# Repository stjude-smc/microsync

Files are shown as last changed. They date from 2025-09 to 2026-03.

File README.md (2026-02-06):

# `microsync` — Microscope Control with Microsecond Precision

**Author:** Roman Kiselev  
**License:** Apache 2.0  
**URL:** [https://github.com/stjude-smc/microsync](https://github.com/stjude-smc/microsync)





## 🚀 Quick Start

Upload `microsync-<x.y.z>.bin` firmware file to Arduino Due (e.g. using [BOSSA](https://github.com/shumatech/BOSSA/releases)).

Install Python `microsync` module.

```python
from microsync import SyncDevice

# Connect to device
sd = SyncDevice("COM4")  # or "/dev/ttyUSB0" on Linux

# Schedule a laser pulse
sd.pos_pulse("D8", 1000, ts=1000)  # 1ms pulse on D8 after 1ms delay
sd.go()  # Start execution
```

**📖 [Full Documentation](https://stjude-smc.github.io/microsync/) | 📓 [Interactive Demo](python/sync%20device%20demo.ipynb)**

## Overview & System Architecture

This project is a high-precision sync device for advanced microscope control, built around an Arduino Due (32-bit ARM Cortex-M3). It combines:

- **Firmware (C++):** Handles real-time event scheduling, pin control, and safety interlocks directly on the microcontroller. Uses a priority queue to manage up to 450 timed events (e.g., laser pulses, camera triggers) with microsecond accuracy.
- **Python API:** Lets you easily talk to the device, schedule events, and run complex acquisition protocols from your computer.

The device connects to your computer via UART (115,200 baud). All timing and pin logic runs on the microcontroller for reliable, low-latency operation.



*Color legend:* green – software components, yellow – microcontroller peripherals, purple – external hardware.

## ✨ Features

- **Microsecond-precision event scheduling** (pulses, toggles, pin set/reset, bursts)
- **Priority event queue** with hardware-timed execution
- **Laser shutter and interlock safety logic**
- **Support for advanced acquisition modes** (continuous, stroboscopic, ALEX)
- **Interactive event visualization** with Bokeh (zoom, pan, hover tooltips)
- **Comprehensive Python API** with logging and context management
- **Extensive examples and documentation in Jupyter notebook**

## 🔧 Hardware

- **Platform:** Arduino Due (32-bit SAM3X8E ARM Cortex-M3 microcontroller)

Arduino Due Board

*Arduino Due board - the hardware platform for microsync*

- **Key Pins: (configurable in `globals.h`)**
  - **Laser shutters:** D8 (Cy2), D9 (Cy3), D10 (Cy5), D11 (Cy7)
  - **Camera trigger:** D7
  - **Error indicator:** D51
  - **Debug pin:** D53
  - **Interlock:** D12 (input), D13 (output). If they are not connected, the laser shutters are disabled.
  - **Burst pulse:** D5
  - **See** `doc/Arduino Due pinout.pdf` and `microsync/src/globals.h` for full pin mapping.
  - **Note** - pins D35-D38 are reserved as inputs for future use. These pins, as well as interlock, error, and debug pins are unavailable as signal outputs because of their special functions.

## Firmware Upload
Upload `microsync-<x.y.z>.bin` to your Arduino Due using BOSSA or Atmel-ICE with Microchip Studio.

### Uploading firmware with BOSSA (no extra hardware required)

1. Download BOSSA from https://github.com/shumatech/BOSSA/releases (pick the right binary for your OS).
2. Connect Due to your computer, use the USB port next to the power jack.
3. Find newly created Arduino Due COM port (e.g. in the Device manager).
4. On your Due, press and hold **Erase** button for at least 0.5 seconds. This will wipe the current firmware and the microcontroller will enter the programming mode.

#### Upload via BOSSA GUI
1. Run BOSSA GUI.
2. Select the correct COM port.
3. Select `microsync-<x.y.z>.bin` file.
4. **Important**: Check the "Boot from Flash" option (this sets GPNVM0=1).
5. Click "Write".

#### Upload via command line
1. Put `bossac.exe` (or `bossac` on Mac/Linux) and `microsync-<x.y.z>.bin` in the same folder.
2. Open a terminal in that folder and run (replace `<COM-PORT>` with the actual COM port of your Due):

```sh
bossac.exe -e -w -v -b microsync-<x.y.z>.bin -p <COM-PORT>
```

### Uploading firmware with Microchip Studio using Atmel-ICE debugger
1. Connect Atmel-ICE SAM connector to JTAG header on your Due.
2. Connect Atmel-ICE to your computer.
3. Power up your Due with a USB cable.
4. Open Microchip Studio.
5. Open the Device Programming dialog (Ctrl+Shift+P).
6. Select Atmel-ICE tool, `ATSAM3X8E` device, JTAG interface, click "Apply".
7. Go to "Memory" tab, select `microsync-{version}.bin` file, click "Program".

### Communication Protocol & Data Structure

The device communicates via UART at 115,200 baud using a fixed-length 24-byte packet format. Each packet contains a command and associated parameters for precise event scheduling. All 24 bytes of a packet must arrive together, with no delay longer than 25 ms between individual bytes; otherwise, the packet is considered incomplete and will be discarded.

Data Packet Structure

**Packet Format:**
- **Command (4 bytes):** 3-character command string, null-terminated
- **Argument 1 (4 bytes):** First parameter (pin index, duration, etc.)
- **Argument 2 (4 bytes):** Second parameter (additional settings)
- **Timestamp (4 bytes):** Scheduled time point of function call, in microseconds
- **Count (4 bytes):** Number of repetitions (0 = infinite)
- **Interval (4 bytes):** Time between repetitions in microseconds

**Startup Message:**
Upon opening of the COM port, the device resets and sends the startup message the includes the firmware version.
```
Sync device is ready. Firmware version: 2.4.0
```

## 🐍 Python Driver

### Installation

Requires Python 3.7+ and `pyserial`.  The `microsync` package is automatically published on Python Package Index (PyPI), so it can be installed with `pip`:

```bash
pip install microsync
```

*Note*: Releases are published to PyPI automatically when a new version is released (a new tag starting with `v` is pushed). The workflow [`.github/workflows/publish-pypi.yml`](.github/workflows/publish-pypi.yml) builds the package from `python/`, sets the version from the tag, and publishes it to PyPI.

### Python Module Structure

The Python driver consists of several modules:

- **`microsync.py`** - Main `SyncDevice` class and communication interface
- **`constants.py`** - Timing constants and system parameters
- **`props.py`** - Property definitions and system settings
- **`rev_pin_map.py`** - Hardware pin mapping (Arduino pin names to internal IDs)
- **`__version__.py`** - Version information and package metadata
- **`sync device demo.ipynb`** - Comprehensive Jupyter notebook with examples

### Basic Usage

```python
from microsync import SyncDevice

# Connect to the device (replace COM4 with your port)
sd = SyncDevice("COM4", log_file='print')  # log_file can be None, 'print', or a filename

# Get device status
print(sd.get_status())
print(sd.version)

# Set and get properties
print(sd.pulse_duration_us)
sd.pulse_duration_us = 1000

# Schedule a positive pulse on pin D8 (Cy2 laser shutter)
sd.pos_pulse("D8", 8000, N=120, interval=50000)
sd.go()
```

### Logging

- Set `log_file='print'` to print all communication.
- Set `log_file='filename.log'` to save to a file.

### Context Manager

Batch multiple commands for precise timing: all commands within the context manager are collected and sent together as a single data packet over UART, ensuring they are processed together on the device. This approach eliminates timing jitter caused by delays or variability in the host operating system, resulting in highly accurate event scheduling.

```python
with sd as dev:
    dev.pos_pulse("D7", 100000, N=10, interval=500000, ts=0)   # Camera trigger
    dev.pos_pulse("D8", 100000, N=10, interval=500000, ts=5000) # Cy2 laser
```

### Event Scheduling

- **Pulse:** `sd.pos_pulse(pin, duration, ts, N, interval)`
- **Toggle:** `sd.tgl_pin(pin, ts, N, interval)`
- **Set/Reset:** `sd.set_pin(pin, level, ts, N, interval)`
- **Enable/Disable Pin:** `sd.enable_pin(pin)`, `sd.disable_pin(pin)`
- **Clear/Stop/Go:** `sd.clear()`, `sd.stop()`, `sd.go()`

#### Event Queue & Execution System

The device uses a **priority queue** to manage event scheduling with microsecond precision. Each data packet received from the host is converted into an internal event structure for scheduling. The most significant change is the conversion of timestamp from 4-byte to 8-byte integer, as well as mapping of pins from name to internal IOPORT index.

**Internal Event Structure (28 bytes):**
- **Function pointer** (4 bytes) — what action to execute (`EventFunc func`)
- **Argument 1** (4 bytes) — first parameter for the function (e.g., pin number)
- **Argument 2** (4 bytes) — second parameter for the function (e.g., duration)
- **Timestamp** (8 bytes) — 64-bit absolute time when to execute (`ts64_cts`)
- **Count** (4 bytes) — number of repetitions remaining (`N`)
- **Interval** (4 bytes) — time between repetitions (`interv_cts`)

**Queue Operation:**
1. **Packet Processing:** 24-byte data packets are converted to 28-byte event structures
2. **Sorting:** Events are automatically sorted by timestamp (earliest first)
3. **Execution:** System timer triggers the next event at its exact timestamp
4. **Repetition:** Events with `N > 1` are rescheduled with updated timestamps
5. **Precision:** Hardware timer ensures microsecond-accurate execution
6. **Capacity:** Up to 450 events can be queued simultaneously

**Example:** When you schedule multiple events, they're automatically ordered and executed in time sequence, regardless of the order they were submitted. If two events have exactly the same timestamp, their execution order is undefined.



### Laser Shutter and Interlock

- **Open/Close shutters:** `sd.open_shutters(mask)`, `sd.close_shutters(mask)`
- **Select lasers:** `sd.selected_lasers = 0b0110` (bitmask: Cy2, Cy3, Cy5, Cy7)
- **Interlock:** `sd.interlock_enabled = True/False`

#### Laser Safety Interlock System

The device includes a sophisticated laser safety interlock that monitors the integrity of the laser safety circuit:

**Hardware Setup:**
- **Output pin (D13):** Sends heartbeat pulses every 25ms
- **Input pin (D12):** Monitors return signal from interlock circuit
- **External circuit:** Required between D12 and D13 for proper operation

**Operation:**
1. **Heartbeat Generation:** System sends pulse train on D13 (HIGH for 1.56ms, LOW for 23.44ms)
2. **Signal Monitoring:** System checks D12 at two critical moments:
   - When output goes LOW (should detect LOW on input)
   - When output goes HIGH (should detect HIGH on input)
3. **Safety Logic:** 
   - **Normal:** Both conditions met → Lasers enabled
   - **Fault:** Either condition fails → Lasers immediately disabled
   - Detects open circuits, short circuits, and missing connections

**Runtime Control:**
```python
sd.interlock_enabled = True  # set to False to ignore the interlock circuit
```

In practice, you want to have normally closed magnetic reed switches (such as [Magnasphere](https://magnasphere.com/product/s-series/)) installed on the doors of the microscope enclosure, connected in series.

### Acquisition Modes

The following high-level acquisition modes are provided as convenience functions for our pTIRF microscopes. Internally, each mode schedules a sequence of low-level events using the common event execution engine described above. This allows you to easily run complex imaging protocols, while retaining precise timing and coordination under the hood:

#### Continuous Imaging
- **Use case:** Continuous illumination with synchronous camera readout
- **Method:** `sd.start_continuous_acq(exp_time, N_frames, ts=0)`
- **Behavior:** Laser shutters remain open during entire acquisition, camera triggered at precise intervals
- **First frame:** Automatically discarded as it contains pre-acquisition noise



The diagram below was created with `EventVisualizer` Python class that uses Bokeh to show actual events scheduled on the microcontroller.


#### Stroboscopic/Timelapse Imaging  
- **Use case:** Brief laser illumination during each camera exposure
- **Method:** `sd.start_stroboscopic_acq(exp_time, N_frames, ts=0, frame_period=0)`
- **Behavior:** Laser pulse synchronized with camera exposure, followed by readout period
- **Timelapse:** Optional waiting period between frames when `frame_period > 0`

Image below shows stroboscopic acquisition diagram with Kinetix camera.



#### ALEX (Alternating Laser Excitation)

> **Note:** For ALEX, select lasers by setting `sd.selected_lasers` in Python (e.g., `sd.selected_lasers = 0b0110`), or send a `SET` command with the `rw_SELECTED_LASERS` property ID (from the `SysProps` enum) over UART.
- **Use case:** Multi-spectral imaging with alternating laser illumination
- **Method:** `sd.start_ALEX_acq(exp_time, N_bursts, ts=0, burst_period=0)`
- **Behavior:** Bursts of frames, each illuminated by different laser channel
- **Timelapse:** Optional waiting period between bursts when `burst_period > 0`

**NOTE** - stroboscopic and ALEX modes use level trigger, which behaves differently on Kinetix and Hamamatsu cameras.
When using Kinetix camera, set the camera triggering mode to "Level trigger overlap mode". It behaves similarly to continuous (rolling shutter) mode, enabling fast imaging. You will have to set Microsync `rw_CAM_LEVEL_TRIGGER_MODE` property to 1 (OVERLAP) to generate correct timings.



When using a Hamamatsu camera, set it to "Level trigger global reset mode" and set the `rw_CAM_LEVEL_TRIGGER_MODE` property to 2 (GLOBAL_RESET) to generate correct timings.



### Status and Events

- **Get all scheduled events:** `sd.get_events(unit="us"|"ms")`
- **Check frames left:** `sd.N_frames_left()`

### Interactive Event Visualization

The `show_events()` method provides interactive visualization of scheduled events using Bokeh:

```python
# Create interactive plot
plot = sd.show_events()

# In Jupyter notebook, plot displays automatically
# Save to file
plot.save_plot("events.html")  # Interactive HTML
plot.save_plot("events.png")   # Static PNG
plot.save_plot("events.svg")   # Vector SVG
```

**Features:**
- **Interactive zoom and pan** - Examine precise timing details
- **Hover tooltips** - See exact timestamps and durations
- **State-based visualization** - Gray boxes show active states (HIGH pins, open shutters)

### Timing Configuration

**Note:** All timing parameters for `microsync` are specified in microseconds (µs).

Configure these timing parameters to match your hardware before starting acquisition:

```python
# Essential timing parameters (in microseconds)
sd.shutter_delay_us = 1300      # Laser shutter opening time
sd.cam_readout_us = 14000       # Camera readout duration (depends on ROI)
sd.pulse_duration_us = 800      # Default pulse duration

# Laser selection (bitmask: Cy2=bit0, Cy3=bit1, Cy5=bit2, Cy7=bit3)
sd.selected_lasers = 0b0110     # Enable Cy3 and Cy5 lasers
```

**Important Notes:**
- `shutter_delay_us` should match your laser shutter's actual opening time. Use an oscilloscope and a photodiode to measure it.
- `cam_readout_us` depends on camera ROI settings. See the camera manual to find out how to calculate or query it.
- Timing values persist between acquisitions until changed. They drop back to defaults after system reset.

## 📚 Examples

See [`python/sync device demo.ipynb`](python/sync%20device%20demo.ipynb) for a comprehensive, step-by-step tutorial with code, explanations, and advanced usage patterns.

## 📋 Properties

| ID | Property | Access | Description |
|----|---|---|---|
| 0  | `version` | Read-only  | Firmware version |
| 1  | `running` | Read-only  | System timer running status |
| 2  | `sys_timer_value` | Read-only  | System timer value (counter ticks) |
| 3  | `sys_timer_ovf_count` | Read-only  | System timer overflow count |
| 4  | `sys_time_ms` | Read-only  | System time (milliseconds) |
| 5  | `prescaler` | Read-only  | System timer prescaler |
| 6  | `pulse_duration_us` | R/W | Default pulse duration (microseconds) |
| 7  | `watchdog_timeout_ms` | Read-only  | Watchdog timeout (ms) |
| 8  | `N_events` | Read-only  | Number of events in queue |
| 9  | `interlock_enabled` | R/W | Laser interlock state (0=disabled) |
| 10 | `selected_lasers` | R/W | Bitmask of enabled laser channels |
| 11 | `open_shutters` | Write-only | Open specified laser shutters |
| 12 | `close_shutters` | Write-only | Close specified laser shutters |
| 13 | `shutter_delay_us` | R/W | Shutter delay (microseconds) |
| 14 | `cam_readout_us` | R/W | Camera readout time (microseconds) |
| 15 | `cam_global_rst` | R/W | Global reset in level trigger mode (bool) |

## 📖 Documentation

📖 **[Full Documentation](https://stjude-smc.github.io/microsync/)** - Complete API reference, user guides, and examples

- **Firmware:** See `microsync/src/` for C++ source and hardware logic.
- **Python API:** See `python/microsync.py` and the Jupyter notebook.
- **Data packet structure:** See `doc/data packet structure.xlsx`.

### Building Documentation

This project includes comprehensive Sphinx/Doxygen documentation that combines Python API documentation with C++ firmware documentation.

#### Prerequisites

**Doxygen:** Required for C++ documentation generation
   - **Windows:** Download and install from [Doxygen website](https://www.doxygen.nl/download.html)
   - **Linux:** `sudo apt-get install doxygen` (Ubuntu/Debian) or `sudo yum install doxygen` (CentOS/RHEL)
   - **macOS:** `brew install doxygen`

#### Building the Documentation

Run the automated build script from the project root:

```bash
python build_docs.py
```

The documentation will be available at `sphinx_docs/_build/html/index.html`. The generated documentation includes:
- **Python API Reference:** Auto-generated from docstrings in the Python modules
- **C++ API Reference:** Generated from firmware header files using Doxygen + Breathe
- **User Guide:** Manual documentation and examples
- **Firmware Architecture:** Detailed explanations of the C++ implementation

The Sphinx documentation automatically builds and deploys to GitHub pages on every push to branches `develop` and `master` via GitHub actions.

## 🔧 Firmware Development

### Building the Firmware

The firmware is built using Microchip Studio or compatible IDEs:

1. **Open the project:** Load `microsync.atsln` in Microchip Studio
2. **Build target:** Select "Release" configuration
3. **Upload:** Use the Atmel ICE debugger, connected via JTAG interface to the microcontroller board. Hit `Ctrl+Shift+P` to open the programming dialog.
4. **Debugging:** If you upload the "Debug" configuration, you can set a breakpoint and pause the code execution on Arduino Due when it's connected via JTAG to Atmel ICE. You will have a normal step-by-step debugging with the direct access to the device registers and memory via Microchip Studio . The caveat is that the hardware timers keep running while you're in the debug mode. Use an oscilloscope when verifying event order and timing in addition to the code debugging.

### Firmware Architecture

- **`main.cpp`:** Entry point and system initialization
- **`globals.h`:** Global definitions, pin mappings, and system settings
- **`events.h/cpp`:** Event scheduling and priority queue management
- **`uart_comm.h/cpp`:** Communication protocol implementation
- **`pins.h/cpp`:** Pin control and hardware abstraction
- **`interlock.h/cpp`:** Laser safety interlock logic (can be disabled)

### Features and Limitations

- **Event queue:** Maximum 450 scheduled events (vs. 4 hardware timers in legacy)
- **Jitter:** Events scheduled within ~10µs of each other may have timing jitter
- **Overload protection:** A watchdog timer automatically resets the system if event queue overflows
- **Interlock:** Requires external circuit between D12 and D13 for laser safety
- **External triggers:** Not available yet, but possible to add. In the future, we could make it so the device reacts to changes on an input pin (like a button press or signal) and schedules events automatically.

**Note:** These limitations are significantly improved compared to the legacy 8-bit version, which had 4.19s exposure limits and 64µs timing resolution.

### Evolution from Legacy `sync_device`
This is the **second generation** of the microscope synchronization device, based on a 32-bit ARM microcontroller (Arduino Due). The first generation was based on Arduino Mega2560 (8-bit ATMega2560) and had fundamental limitations:

**Key Changes and Improvements in 32-bit Version:**
- **3.3V** logic – Arduino Due uses 3.3V CMOS logic levels for digital I/O, whereas the Arduino Mega2560 uses 5V logic levels
- **Microsecond precision** (vs. 64µs steps in 8-bit version)
- **No 4.19s exposure time limit** (vs. 16-bit timer limitation)
- **Event-driven architecture** with priority queue (vs. fixed state machine)
- **Up to 450 scheduled events** (vs. limited to 4 hardware timers)
- **Advanced acquisition modes** with precise timing control
- **Safety interlocks** for laser protection
- **Modern Python API** with context management and logging

**Legacy Repository:** The original 8-bit version is available at [sync_device_8bit_legacy](https://github.com/stjude-smc/sync_device_8bit_legacy) for reference.

## 📝 License

Apache 2.0.  
(c) Roman Kiselev, St. Jude Children's Research Hospital

## 🙏 Acknowledgments

- Based on Atmel SAM3X8E microcontroller (Arduino Due board)
- Uses `ASF` (Atmel Software Framework)
- See `/doc` for datasheets and pinouts

---

**For questions or contributions, please open an issue or pull request on [GitHub](https://github.com/stjude-smc/microsync).**

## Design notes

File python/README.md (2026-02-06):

# `microsync` — Python driver for microscope synchronization device

**Python driver for `microsync` — a universal 32-bit Arduino Due-based triggering device**. Control lasers, cameras, and timing with microsecond precision.

- **Full documentation:** [stjude-smc.github.io/microsync](https://stjude-smc.github.io/microsync/)
- **Repository:** [github.com/stjude-smc/microsync](https://github.com/stjude-smc/microsync)

## Install

Requires Python 3.7+ and `pyserial` (installed automatically):

```bash
pip install microsync
```

## Quick start

Upload the microsync firmware to an Arduino Due, then:

```python
from microsync import SyncDevice

sd = SyncDevice("COM4")   # or "/dev/ttyUSB0" on Linux
sd.pos_pulse("D8", 1000, ts=1000)   # 1 ms pulse on D8 after 1 ms delay
sd.go()
```

## Features

- Microsecond-precision event scheduling (pulses, toggles, camera triggers)
- Laser shutter and interlock safety logic
- Acquisition modes: continuous, stroboscopic, ALEX
- Interactive event visualization (Bokeh)
- Context manager for jitter-free batch commands

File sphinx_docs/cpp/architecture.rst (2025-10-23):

C++ Firmware Architecture
=========================

Overview
--------

The microsync firmware is built on the Arduino Due platform using the SAM3X8E ARM Cortex-M3 microcontroller. The firmware provides microsecond-precision timing control for microscope synchronization with a focus on safety, reliability, and performance.

System Architecture
-------------------

System architecture diagram

Color legend: green – software components, yellow – microcontroller peripherals, purple – external hardware.

Core Components
---------------

Event System
^^^^^^^^^^^^

The heart of the synchronization system is the priority queue-based event scheduler:

- **Priority Queue**: Orders events by timestamp for precise execution
- **Event Processing**: Handles up to 450 scheduled events
- **Microsecond Precision**: 64-bit timestamp system with overflow handling
- **Real-time Execution**: Interrupt-driven event processing

.. code-block:: cpp

   // Event structure for priority queue
   struct Event {
       uint8_t func;           // Function to execute
       uint8_t arg1, arg2;     // Function arguments
       uint64_t ts64_cts;      // 64-bit timestamp in clock ticks
       uint16_t N;             // Number of repetitions
       uint32_t interv_cts;    // Interval between repetitions
   };

Communication System
^^^^^^^^^^^^^^^^^^^^

UART-based communication protocol for host-device interaction:

- **Baud Rate**: 115,200 bps
- **Protocol**: Command-response with error handling
- **Buffer Management**: Ring buffer with overflow protection
- **Timeout Handling**: Automatic detection of incomplete transmissions

.. code-block:: cpp

   // UART communication functions
   void init_uart_comm(void);
   void uart_tx(const char* data, uint16_t len);
   void process_uart_rx(void);

Safety Systems
^^^^^^^^^^^^^^

Laser safety interlock system with hardware and software protection:

- **Hardware Interlock**: D12/D13 circuit monitoring
- **Software Timer**: 1.56ms heartbeat generation
- **Automatic Shutdown**: Disables lasers on interlock failure
- **Runtime Control**: Enable/disable via software

.. code-block:: cpp

   // Interlock control functions
   void init_interlock(void);
   void enable_lasers(void);
   void disable_lasers(void);

Hardware Interface
^^^^^^^^^^^^^^^^^^

Pin management and hardware abstraction layer:

- **Pin Mapping**: Arduino Due pin assignments
- **Laser Shutters**: D8 (Cy2), D9 (Cy3), D10 (Cy5), D11 (Cy7) - see ``globals.h``
- **Camera Trigger**: D7 - see ``globals.h``
- **Status LEDs**: Visual feedback and debugging

.. code-block:: cpp

   // Pin control functions
   void init_pins(void);
   void set_pin(uint8_t pin, bool state);
   void toggle_pin(uint8_t pin);

Memory Management
-----------------

Optimized memory usage for embedded constraints:

- **Static Allocation**: Pre-allocated buffers and structures
- **Stack Management**: Careful stack usage monitoring
- **Heap Protection**: Out-of-memory handler with error reporting
- **Buffer Sizes**: Optimized for typical use cases

.. code-block:: cpp

   // Memory management
   #define MAX_N_EVENTS 450
   #define UART_BUFFER_SIZE 256
   #define WATCHDOG_TIMEOUT 1000  // ms

Error Handling
--------------

Comprehensive error detection and recovery:

- **Watchdog Timer**: System reset on software hang
- **Hard Fault Handler**: Graceful handling of hardware errors
- **UART Error Reporting**: Real-time error communication
- **LED Status**: Visual error indication

.. code-block:: cpp

   // Error handling functions
   void activate_watchdog(void);
   void err_led_on(void);
   void out_of_memory_handler(void);

Performance Characteristics
---------------------------

- **Event Scheduling**: Up to 450 events
- **Timing Precision**: Microsecond accuracy
- **Response Time**: < 1ms command processing
- **Memory Usage**: < 32KB RAM
- **CPU Utilization**: < 10% typical load

Build System
------------

The firmware is built using Microchip Studio with the following configuration:

- **Target**: Arduino Due (SAM3X8E)
- **Compiler**: ARM GCC
- **Optimization**: -O2 for performance
- **Debugging**: Full debug symbols in Debug build
- **Release**: Optimized for production use

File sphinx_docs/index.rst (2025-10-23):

Welcome to microsync documentation!
==========================================

**Version:** |version|  
**Author:** Roman Kiselev  
**License:** Apache 2.0

A high-precision synchronization device for advanced microscope control, based on a 32-bit ARM microcontroller (Arduino Due).

`View on GitHub <https://github.com/stjude-smc/microsync>`_

.. toctree::
   :maxdepth: 2
   :caption: Contents:

   installation
   quickstart
   api/index
   cpp/architecture
   cpp/firmware
   cpp_api/library_root

Overview
--------

This project provides firmware and a Python driver for a high-precision synchronization device designed for advanced microscope control. The device enables precise timing and coordination of lasers, shutters, cameras, and other peripherals with microsecond precision.

Key Features
^^^^^^^^^^^^

* **Microsecond-precision event scheduling** with priority queue system
* **Laser shutter and interlock safety logic**
* **Advanced acquisition modes** (continuous, stroboscopic, ALEX)
* **Comprehensive Python API** with logging and context management
* **Event-driven architecture** supporting up to 450 scheduled events
* **Safety interlocks** for laser protection

Hardware Platform
^^^^^^^^^^^^^^^^^

* **Microcontroller:** Arduino Due (SAM3X8E ARM Cortex-M3)
* **Logic Levels:** 3.3V CMOS
* **Communication:** UART at 115,200 baud
* **Key Pins:** Laser shutters (D8-D11), Camera trigger (D7), Interlock (D12/D13)

Python API
^^^^^^^^^^

The Python driver provides a high-level interface for controlling the device:

.. code-block:: python

   from microsync import SyncDevice
   
   # Connect to device
   sd = SyncDevice("COM4")
   
   # Schedule events
   sd.pos_pulse("D8", 1000, N=10, interval=50000)  # Pulse on D8 (Cy2 laser)
   sd.go()

For detailed API documentation, see :doc:`api/index`.

Installation
^^^^^^^^^^^^

.. code-block:: bash

   pip install pyserial
   # Copy python/ directory to your project

For complete installation instructions, see :doc:`installation`.

Quick Start
^^^^^^^^^^^

1. Connect laser shutters and cameras to the Arduino Due pins. Use LED during testing.
1. Connect Arduino Due via USB
2. Install Python dependencies
3. Import and use the SyncDevice class
4. Schedule events and start acquisition

See :doc:`quickstart` for a step-by-step guide.

Indices and tables
==================

* :ref:`genindex`
* :ref:`modindex`
* :ref:`search`

.. _GitHub: https://github.com/stjude-smc/microsync

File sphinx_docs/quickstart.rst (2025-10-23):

Quick Start Guide
=================

This guide will get you up and running with microsync in minutes. It covers the basic setup and common usage patterns.

Basic Setup
-----------

1. **Install the Python driver:**

   .. code-block:: bash

      pip install pyserial
      # Copy the python/ directory to your project

2. **Connect your Arduino Due:**

   .. code-block:: python

      from microsync import SyncDevice
      
      # Connect to device (replace COM4 with your port)
      sd = SyncDevice("COM4")
      print(f"Connected! Firmware version: {sd.version}")

Basic Event Scheduling
----------------------

**Simple Pulse Generation:**

.. code-block:: python

   # Generate a 1ms pulse on pin A0
   sd.pos_pulse("A0", 1000)
   sd.go()

**Repeating Events:**

.. code-block:: python

   # Generate 10 pulses, 1ms each, every 50ms
   sd.pos_pulse("A0", 1000, N=10, interval=50000)
   sd.go()

**Multiple Events:**

.. code-block:: python

   # Schedule multiple events
   sd.pos_pulse("A0", 1000, ts=0)      # At t=0
   sd.pos_pulse("A1", 1000, ts=5000)   # At t=5ms
   sd.pos_pulse("A2", 1000, ts=10000)  # At t=10ms
   sd.go()

**Using Context Manager for Precise Timing:**

.. code-block:: python

   # Batch commands for precise timing
   with sd as dev:
       dev.pos_pulse("A0", 1000, ts=0)
       dev.pos_pulse("A1", 1000, ts=5000)
       dev.pos_pulse("A2", 1000, ts=10000)
   # All commands sent together

Laser Control
--------------

**Basic Laser Shutter Control:**

.. code-block:: python

   # Open all laser shutters
   sd.open_shutters()
   
   # Close specific shutters (Cy2 and Cy5)
   sd.close_shutters(1 | 4)
   
   # Select which lasers are enabled
   sd.selected_lasers = 0b0110  # Enable Cy3 and Cy5

**Laser Interlock:**

.. code-block:: python

   # Check interlock status
   print(f"Interlock enabled: {sd.interlock_enabled}")
   
   # Disable interlock (for testing only)
   sd.interlock_enabled = False

Acquisition Modes
-----------------

**Continuous Imaging:**

.. code-block:: python

   # Configure timing
   sd.shutter_delay_us = 1300
   sd.cam_readout_us = 14000
   
   # Start continuous acquisition
   sd.start_continuous_acq(exp_time=200000, N_frames=15)
   sd.go()

**Stroboscopic Imaging:**

.. code-block:: python

   # Start stroboscopic acquisition
   sd.start_stroboscopic_acq(exp_time=200000, N_frames=15)
   sd.go()

**ALEX (Multi-spectral) Imaging:**

.. code-block:: python

   # Select lasers for ALEX
   sd.selected_lasers = 0b1111  # All lasers
   
   # Start ALEX acquisition
   sd.start_ALEX_acq(exp_time=50000, N_bursts=9)
   sd.go()

System Control
--------------

**Start/Stop Control:**

.. code-block:: python

   # Start processing events
   sd.go()
   
   # Stop processing (events remain in queue)
   sd.stop()
   
   # Resume processing
   sd.go()

**Event Management:**

.. code-block:: python

   # Clear all scheduled events
   sd.clear()
   
   # Check how many events are scheduled
   print(f"Events in queue: {sd.N_events}")
   
   # Get list of scheduled events
   events = sd.get_events("us")
   for event in events:
       print(f"{event.func} at {event.ts} {event.unit}")

**System Status:**

.. code-block:: python

   # Get detailed status
   print(sd.get_status())
   
   # Check if system is running
   print(f"System running: {sd.running}")
   
   # Get current system time
   print(f"System time: {sd.sys_time_s:.3f} seconds")

Configuration
-------------

**Timing Parameters:**

.. code-block:: python

   # Set default pulse duration
   sd.pulse_duration_us = 800
   
   # Set camera readout time
   sd.cam_readout_us = 14000
   
   # Set shutter delay
   sd.shutter_delay_us = 1300

**Logging:**

.. code-block:: python

   # Enable communication logging
   sd = SyncDevice("COM4", log_file="sync.log")
   
   # Or print to terminal
   sd = SyncDevice("COM4", log_file="print")

Common Patterns
---------------

**Timelapse Acquisition:**

.. code-block:: python

   # Stroboscopic with timelapse
   sd.start_stroboscopic_acq(
       exp_time=200000, 
       N_frames=5, 
       frame_period=1500000  # 1.5s between frames
   )
   sd.go()

**Multi-channel Control:**

.. code-block:: python

   # Control multiple pins simultaneously
   with sd as dev:
       dev.pos_pulse("D8", 1000, ts=0)      # Cy2 laser
       dev.pos_pulse("D9", 1000, ts=1000)   # Cy3 laser
       dev.pos_pulse("D10", 1000, ts=2000)  # Cy5 laser
       dev.pos_pulse("D7", 100, ts=500)     # Camera trigger

**Error Handling:**

.. code-block:: python

   try:
       sd = SyncDevice("COM4")
       sd.pos_pulse("A0", 1000)
       sd.go()
   except Exception as e:
       print(f"Error: {e}")
       # Handle error appropriately

Next Steps
----------

Now that you have the basics:

1. **Explore the API:** See :doc:`api/index` for complete documentation
2. **Try examples:** Check the Jupyter notebook for more complex scenarios
3. **Learn about hardware:** Review the README for connection details
4. **Understand firmware:** See the source code for technical details

**Need help?** Open an issue on GitHub or check the README.

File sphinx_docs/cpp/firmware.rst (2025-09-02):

Firmware Build and Deployment
=============================

Building the Firmware
---------------------

Prerequisites
^^^^^^^^^^^^^

- **Microchip Studio** (free download from Microchip)
- **Arduino Due board**
- **micro-USB cable**
- **Atmel ICE debugger** (optional, for debugging)

Project Structure
^^^^^^^^^^^^^^^^^

.. code-block:: text

   microsync/
   ├── main.cpp                # Main application entry point
   ├── src/
   │   ├── globals.h           # Global definitions and constants
   │   ├── events.h/cpp        # Event system implementation
   │   ├── uart_comm.h/cpp     # UART communication
   │   ├── interlock.h/cpp     # Laser safety interlock
   │   ├── pins.h/cpp          # Pin management
   │   ├── props.h/cpp         # System properties
   │   └── ASF/                # Atmel Software Framework
   └── microsync.atsln         # Microchip Studio solution

Build Configuration
^^^^^^^^^^^^^^^^^^^

**Debug Configuration:**

- Full debug symbols, you can set breakpoints in the code and step through the code running on the board.
- Optimization disabled
- Development and testing

**Release Configuration:**

- Optimized for performance (-O2)
- Minimal debug information, no breakpoints can be set.
- Production deployment
- Reduced memory footprint

Build Steps
^^^^^^^^^^^

1. **Open** `microsync.atsln` in Microchip Studio.
2. **Select** Debug or Release config (target: Arduino Due).
3. **Build** (F7).  
4. **Check** for `microsync.bin` in Debug/ or Release/ folder.

Upload Methods
--------------

See the :doc:`../installation#firmware-upload` section in the installation guide.

Troubleshooting
---------------

Common Issues
^^^^^^^^^^^^^

**Build Errors:**

- Check ASF framework installation
- Verify include paths
- Ensure all source files are included

**Upload Failures:**

- Check USB connection
- Verify COM port settings
- Ensure Arduino Due is in programming mode

**Runtime Issues:**

- Check power supply
- Verify pin connections
- Monitor UART output for errors

Debugging
---------

Debug Features
^^^^^^^^^^^^^^

- **Breakpoints:** Set in Microchip Studio
- **Variable Watch:** Real-time value inspection
- **Call Stack:** Function call history
- **Memory Inspection:** RAM and register values

Note that pausing the program will not stop the running system timers, and you're likely to miss scheduled events.

Version Management
------------------

Version Information
^^^^^^^^^^^^^^^^^^^

The firmware version is defined in `globals.h`:

.. code-block:: cpp

   #define VERSION "2.4.0"

Version Compatibility
^^^^^^^^^^^^^^^^^^^^^

- **Python Driver**: Must match major and minor firmware version
- **Protocol**: Backward compatible within major versions
- **Features**: New features require updates to Python driver

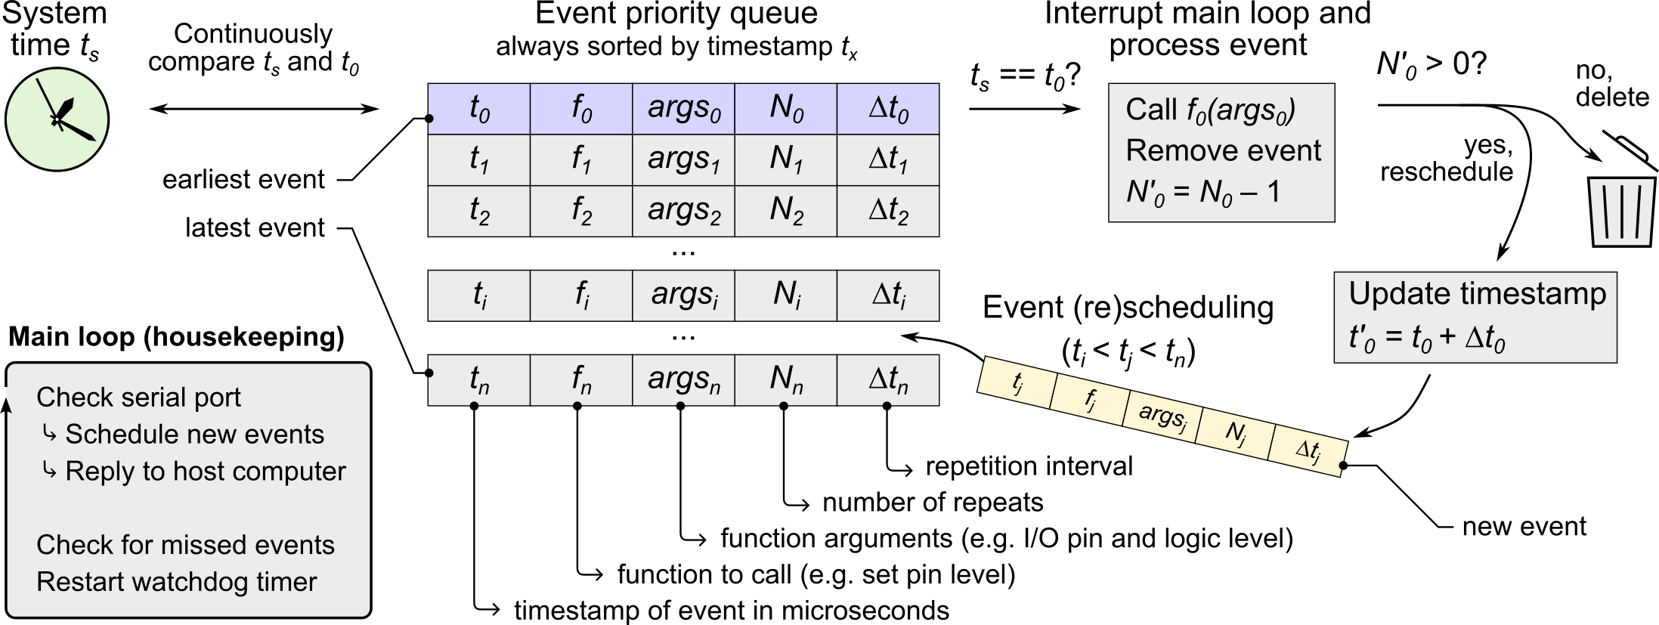
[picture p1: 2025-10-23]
doc/scheduler_architecture.png

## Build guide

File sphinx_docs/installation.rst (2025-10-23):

Installation Guide
==================

This guide covers the installation and setup of the microsync project, including both the Python driver and firmware.

Python Driver Installation
--------------------------

Prerequisites
^^^^^^^^^^^^^

* Python 3.7 or higher
* pip package manager
* Serial port access (for device communication)

Install Dependencies
^^^^^^^^^^^^^^^^^^^^

Install the required Python packages:

.. code-block:: bash

   pip install pyserial

Install the microsync Driver
^^^^^^^^^^^^^^^^^^^^^^^^^^^^^^^^^

**Option 1: Copy the Python directory**

.. code-block:: bash

   # Clone or download the repository
   git clone https://github.com/stjude-smc/microsync.git
cd microsync
   
   # Copy the python directory to your project
   cp -r python/ /path/to/your/project/
   
   # Or add to your Python path
   export PYTHONPATH="${PYTHONPATH}:/path/to/microsync/python"

**Option 2: Install as a package (recommended for development)**

.. code-block:: bash

   # From the project root directory
   pip install -e .

Verify Installation
^^^^^^^^^^^^^^^^^^^

Test that the driver can be imported:

.. code-block:: python

   from microsync import SyncDevice
   print("Installation successful!")

Firmware Installation
---------------------

Prerequisites
^^^^^^^^^^^^^

* Microchip Studio (free download from Microchip)
* Arduino Due board
* USB cable
* Atmel ICE debugger (optional, for debugging)

Build the Firmware
^^^^^^^^^^^^^^^^^^

1. **Open the project in Microchip Studio:**

   .. code-block:: bash

      # Open the solution file
      microsync.atsln

2. **Configure build settings:**

   - Set build target to "Release"
   - Ensure all dependencies are resolved

3. **Build the project:**

   - Press F7 or use Build → Build Solution
   - Verify successful compilation

Firmware Upload
^^^^^^^^^^^^^^

Upload `microsync-<x.y.z>.bin` to your Arduino Due using BOSSA or Atmel-ICE with Microchip Studio.

**Method 1: Using BOSSA (Recommended - No Extra Hardware Required)**

1. Download BOSSA from https://github.com/shumatech/BOSSA/releases (pick the right binary for your OS)
2. Connect Due to your computer, use the USB port next to the power jack
3. Find newly created Arduino Due COM port (e.g. in the Device manager)
4. On your Due, press and hold **Erase** button for at least 0.5 seconds. This will wipe the current firmware and the microcontroller will enter the programming mode

**Upload via BOSSA GUI:**

1. Run BOSSA GUI
2. Select the correct COM port
3. Select `microsync-<x.y.z>.bin` file
4. **Important**: Check the "Boot from Flash" option (this sets GPNVM0=1)
5. Click "Write"

**Upload via command line:**

1. Put `bossac.exe` (or `bossac` on Mac/Linux) and `microsync-<x.y.z>.bin` in the same folder
2. Open a terminal in that folder and run (replace `<COM-PORT>` with the actual COM port of your Due):

   .. code-block:: sh

      bossac.exe -e -w -v -b microsync-<x.y.z>.bin -p <COM-PORT>

**Method 2: Using Microchip Studio with Atmel-ICE Debugger**

1. Connect Atmel-ICE SAM connector to JTAG header on your Due
2. Connect Atmel-ICE to your computer
3. Power up your Due with a USB cable
4. Open Microchip Studio
5. Open the Device Programming dialog (Ctrl+Shift+P)
6. Select Atmel-ICE tool, `ATSAM3X8E` device, JTAG interface, click "Apply"
7. Go to "Memory" tab, select `microsync-{version}.bin` file, click "Program"

Hardware Setup
--------------

Required Connections
^^^^^^^^^^^^^^^^^^^^

* **USB Connection:** Connect Arduino Due to host computer
* **Laser Shutters:** D8 (Cy2), D9 (Cy3), D10 (Cy5), D11 (Cy7) - configurable in ``globals.h``
* **Camera Trigger:** D7 - configurable in ``globals.h``
* **Interlock Circuit:** Connect between D12 (input) and D13 (output)

Power Supply
^^^^^^^^^^^^

The device is powered through the USB connection. No external power supply is required.

Driver Installation (Windows)
^^^^^^^^^^^^^^^^^^^^^^^^^^^^^

1. Download Arduino drivers from `arduino.cc <https://www.arduino.cc/en/software>`_
2. Install the drivers when prompted
3. The device will appear as "Arduino Due" in Device Manager

Verification
------------

Test the Complete Setup
^^^^^^^^^^^^^^^^^^^^^^^

1. **Connect the device:**

   .. code-block:: python

      from microsync import SyncDevice
      
      # Connect to device (replace COM4 with your port)
      sd = SyncDevice("COM4")
      print(f"Connected to device version: {sd.version}")

2. **Test basic functionality:**

   .. code-block:: python

      # Test event scheduling
      sd.pos_pulse("D8", 1000, N=5, interval=10000)  # Pulse on D8 (Cy2 laser)
      sd.go()
      
      # Check status
      print(sd.get_status())

3. **Verify communication:**

   .. code-block:: python

      # Test property access
      print(f"System timer running: {sd.running}")
      print(f"Number of events: {sd.N_events}")

Troubleshooting
---------------

Common Issues
^^^^^^^^^^^^^

**Connection Error:**
- Verify correct COM port
- Check USB cable connection
- Ensure drivers are installed

**Version Mismatch:**
- Update firmware to match Python driver version
- Check version compatibility

**Permission Errors:**
- Run as administrator (Windows)
- Check serial port permissions (Linux/Mac)

**Build Errors:**
- Verify Microchip Studio installation
- Check ASF (Atmel Software Framework) installation
- Ensure all dependencies are resolved

Getting Help
^^^^^^^^^^^^

* Check the README for troubleshooting tips
* Review the README for hardware documentation
* Open an issue on `GitHub <https://github.com/stjude-smc/microsync>`_

Next Steps
----------

After successful installation:

1. Read the :doc:`quickstart` guide
2. Explore the :doc:`api/index` documentation
3. Try the examples in the Jupyter notebook
4. Review the README for hardware setup

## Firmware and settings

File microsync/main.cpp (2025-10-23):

/*/
 * main.cpp - Entry point to microsync firmware
 */ 

extern "C" {
	#include "asf.h"
}

#include <new>  // to set custom out-of-memory handler

#include "globals.h"
#include "uart_comm.h"
#include "events.h"
#include "interlock.h"
#include "props.h"


/**
 * @brief Activates the watchdog timer with a configurable timeout
 * 
 * Initializes the watchdog timer with a timeout value calculated from WATCHDOG_TIMEOUT.
 * The watchdog will trigger a system reset if not kicked within the timeout period.
 */
void activate_watchdog(void) {
	// Calculate the WDT counter value for 1 second timeout
	uint32_t timeout_value = wdt_get_timeout_value(WATCHDOG_TIMEOUT * 1000, BOARD_FREQ_SLCK_XTAL);
	
	if (timeout_value == WDT_INVALID_ARGUMENT)
	{
		printf("ERR: Can't activate watchdog for timeout of %lu us\n", WATCHDOG_TIMEOUT * 1000);
		return;
	}

	uint32_t wdt_mode = WDT_MR_WDFIEN;
	// Initialize WDT with the calculated timeout value
	wdt_init(WDT, wdt_mode, timeout_value, timeout_value);
	
	NVIC_EnableIRQ(WDT_IRQn);
	NVIC_SetPriority(WDT_IRQn, 0);
}




/**
 * @brief Handles out-of-memory errors from the C++ new operator
 * 
 * This function is called when the system runs out of memory during dynamic allocation.
 * It turns on the error LED, prints an error message, and aborts the program.
 */
void out_of_memory_handler() {
	err_led_on();
	// Handle out-of-memory error here
	printf("ERR: out of memory!\n");
	// You can abort or take other actions
	std::abort();
}


/**
 * @brief Handles hard fault exceptions
 * 
 * This function is called when a hard fault occurs (e.g., accessing invalid memory).
 * It turns on the error LED, sends an error message over UART, and performs a processor reset.
 */
extern "C" void HardFault_Handler() {
	err_led_on();
	const char err_msg[] = "ERR - function at `nullptr` address has been called; restarting system!\n";
	
	pdc_packet_t uart_tx_packet;
	uart_tx_packet.ul_addr = (uint32_t) err_msg;
	uart_tx_packet.ul_size = sizeof(err_msg);
	pdc_tx_init(uart_get_pdc_base(UART), &uart_tx_packet, nullptr);
	
	delay_ms(50);
	RSTC->RSTC_CR = 0xA5000000 | RSTC_CR_PROCRST;  // processor reset
}


extern "C" {
	// Implementation of _write function for printf
	// NOTE: printf is buffered and sends data out after \n symbol
	/**
	 * @brief Implementation of _write function for printf support
	 * @param file File descriptor (unused)
	 * @param ptr Pointer to data to write
	 * @param len Length of data to write
	 * @return Number of bytes written
	 * 
	 * This function enables printf to work by redirecting output to UART.
	 * Note: printf is buffered and sends data out after \n symbol.
	 */
	int _write(int file, char *ptr, int len) {
		uart_tx(ptr, len);
		return len;
	}

	/**
	 * @brief Implementation of _read function for stdio compatibility
	 * @param file File descriptor (unused)
	 * @param ptr Pointer to read buffer (unused)
	 * @param len Length to read (unused)
	 * @return Always returns 0 (no data read)
	 * 
	 * This is a minimal implementation for stdio compatibility.
	 * It doesn't actually read any data from any source.
	 */
	int _read(int file, char *ptr, int len) {
		// This is a minimal implementation; it doesn't actually read any data.
		// It needs to return the number of bytes read (0 in this case).
		return 0;
	}
}




/************************************************************************/
/*                       ENTRY POINT                                    */
/************************************************************************/
/**
 * @brief Main entry point for the microsync firmware
 * @return Never returns (infinite loop)
 * 
 * Initializes all system components, starts the system timer, and enters the main event loop.
 * The main loop processes events, polls UART for commands, and kicks the watchdog timer.
 */
int main() {
	activate_watchdog();
	
	// Set out of memory handler for `new` operator. This will send error
	// message over UART
	std::set_new_handler(out_of_memory_handler);
	
	// Set buffer size for printf
	setvbuf(stdout, NULL, _IOLBF, UART_BUFFER_SIZE);

	// Initialize all peripheral systems
	sysclk_init();
	board_init();
	init_uart_comm();
	init_pins();	
	init_sys_timer();
	init_burst_timer();
	
	init_props();
	
	init_interlock();
	
	printf("Sync device is ready. Firmware version: %s\n", VERSION);
	
	start_sys_timer();

	while (1) {
		if (is_event_missed())
		{
			err_led_on();
			process_events();  // <- internally sets RA to timestamp of the next event
		}

		poll_uart();

		// Indicates execution of the main loop (for monitoring with an oscilloscope)
		dbg_pin_up();
		dbg_pin_dn();

		wdt_restart(WDT); // Kick the watchdog
	}
}



/**
 * @brief Watchdog timer interrupt handler
 * 
 * This function is called when the watchdog timer expires (system timeout).
 * It turns on the error LED, sends an error message over UART, and performs a processor reset.
 */
void WDT_Handler(void)
{
	err_led_on();
	const char err_msg[] = "ERR - watchdog timeout; restarting system!\n";
	
	pdc_packet_t uart_tx_packet;
	uart_tx_packet.ul_addr = (uint32_t) err_msg;
	uart_tx_packet.ul_size = sizeof(err_msg);
	pdc_tx_init(uart_get_pdc_base(UART), &uart_tx_packet, nullptr);
	
	delay_ms(50);

	RSTC->RSTC_CR = 0xA5000000 | RSTC_CR_PROCRST;  // processor reset
}

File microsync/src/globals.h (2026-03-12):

/**
 * @file globals.h
 * @author Roman Kiselev (roman.kiselev@stjude.org)
 * @brief Global system definitions: pinouts and settings.
 */
#pragma once

#ifndef UNIT_TEST
#include <ioport.h>
#include "pins.h"
#endif

#define VERSION "2.6.4"


/************************************************************************/
/*                    PINOUT AND WIRING DEFINITIONS                     */
/************************************************************************/
// Laser shutters
#define CY2_PIN		PIO_PC22_IDX	// D8
#define CY3_PIN		PIO_PC21_IDX	// D9
#define CY5_PIN		PIO_PA28_IDX	// D10
#define CY7_PIN		PIO_PD7_IDX  	// D11

#define CY2_SECONDARY_PIN PIO_PC2_IDX	// D34
#define CY3_SECONDARY_PIN PIO_PC1_IDX	// D33
#define CY5_SECONDARY_PIN PIO_PD10_IDX	// D32
#define CY7_SECONDARY_PIN PIO_PA7_IDX	// D31

#define SECONDARY_SHUTTER_DELAY 5000UL  // delay of the secondary shutters, in us. We assume it's mechanical

const uint32_t shutter_pins[] = { CY2_PIN, CY3_PIN, CY5_PIN, CY7_PIN };
const uint32_t shutter_secondary_pins[] = { CY2_SECONDARY_PIN, CY3_SECONDARY_PIN, CY5_SECONDARY_PIN, CY7_SECONDARY_PIN };

#define CAMERA_PIN  PIO_PC23_IDX    // D7

// Error indicator trigger
#define ERR_PIN		PIO_PC12_IDX	// D51

/**
 * @brief Turn on the error indicator LED.
 * 
 * Sets the error LED pin high to indicate an error condition.
 * The LED is connected to pin D53 on the Arduino Due.
 */
inline void err_led_on(){
	ioport_set_pin_level(ERR_PIN, 1);
}

/**
 * @brief Turn off the error indicator LED.
 * 
 * Sets the error LED pin low to clear the error indication.
 * The LED is connected to pin D53 on the Arduino Due.
 */
inline void err_led_off(){
	ioport_set_pin_level(ERR_PIN, 0);
}

// Debug pin
#define DBG_PIN  PIO_PB14_IDX        // D53

/**
 * @brief Set the debug pin high.
 * 
 * Sets the debug pin high for debugging and timing measurements.
 * The debug pin is connected to D31 on the Arduino Due.
 */
inline void dbg_pin_up(){
	ioport_set_pin_level(DBG_PIN, 1);
}

/**
 * @brief Set the debug pin low.
 * 
 * Sets the debug pin low for debugging and timing measurements.
 * The debug pin is connected to D31 on the Arduino Due.
 */
inline void dbg_pin_dn(){
	ioport_set_pin_level(DBG_PIN, 0);
}

// Burst pulse train pin
#define BURST_PIN    PIO_PC25_IDX	// D5, TIOA6  (TC2, channel 0)


// Interlock configuration (see datasheet table 36-4)
#define INTLCK_IN		      PIO_PD8_IDX   // D12

#define INTLCK_OUT       	  PIO_PB27_IDX      // D13, TIOB0  (TC0, channel 0)
#define INTLCK_OUT_PERIPH     IOPORT_MODE_MUX_B

#define ID_INTLCK_TC          ID_TC0
#define INTLCK_TC             TC0	// ID / 3
#define INTLCK_TC_CH          0		// ID % 3
#define INTLCK_TC_Handler     TC0_Handler
#define INTLCK_TC_IRQn		  TC0_IRQn
#define INTLCK_TC_PERIOD_US	  25000UL

/************************************************************************/
/*                    UART AND DMA CONFIGURATION                        */
/************************************************************************/
#define UART_BUFFER_SIZE 512   // Size of DMA-controlled UART buffers
#define UART_BAUDRATE 115200   // bits per second
#define UART_TIMEOUT  25       // ms - timeout for UART communication
// UART uses timer 4 (module TC1 channel 1)
#define ID_UART_TC           ID_TC4
#define UART_TC              TC1	// ID / 3
#define UART_TC_CH           1		// ID % 3
#define UART_TIMEOUT_Handler TC4_Handler
#define UART_TC_IRQn	     TC4_IRQn


/************************************************************************/
/*                      EVENT HANDLING                                  */
/************************************************************************/
#define WATCHDOG_TIMEOUT  100UL  // ms

// Maximum allowed number of events in the event table
#define MAX_N_EVENTS	450UL

// Uniform time delay added to every single scheduled event, us
// It should be long enough to ensure correct event processing
// under any circumstance
#define UNIFORM_TIME_DELAY 500UL

// Minimal interval between two subsequent runs of the same events, us
#define MIN_EVENT_INTERVAL 20UL

// Grace period for event processing - any event within this interval gets fired
#define TS_TOLERANCE        2UL   // us
#define TS_MISSED_TOLERANCE 100UL // us - when we decide the event has been missed


/************************************************************************/
/*    SYSTEM TIMER CONFIGURATION AND TIME CONVERSION FUNCTIONS          */
/************************************************************************/

// Timer prescaler configuration. See SAM3X TC_CMR register, datasheet p883
// Options are 2, 8, 32, and 128
#define PRESC32

#ifdef PRESC2    // 1ct = 24ns, overflow after 102s  (1min 42s)
#define SYS_TC_PRESCALER 2UL
#define SYS_TC_CMR_TCCLKS_TIMER_CLOCK TC_CMR_TCCLKS_TIMER_CLOCK1
#endif

#ifdef PRESC8    // 1ct = 95ns, overflow after 409s  (6min 49s)
#define SYS_TC_PRESCALER 8UL
#define SYS_TC_CMR_TCCLKS_TIMER_CLOCK TC_CMR_TCCLKS_TIMER_CLOCK2
#endif

#ifdef PRESC32   // 1ct = 381ns, overflow after 1636s (27min 16s)
#define SYS_TC_PRESCALER 32UL
#define SYS_TC_CMR_TCCLKS_TIMER_CLOCK TC_CMR_TCCLKS_TIMER_CLOCK3
#endif

#ifdef PRESC128  // 1ct = 1524ns, overflow after 6544s (1h 49min)
#define SYS_TC_PRESCALER 128UL
#define SYS_TC_CMR_TCCLKS_TIMER_CLOCK TC_CMR_TCCLKS_TIMER_CLOCK4
#endif

#define SYS_TC_CONVERSION_MULTIPLIER (8400000UL/SYS_TC_PRESCALER)
#define TS_TOLERANCE_CTS (TS_TOLERANCE * SYS_TC_CONVERSION_MULTIPLIER / 100000UL)
#define TS_MISSED_TOLERANCE_CTS (TS_MISSED_TOLERANCE * SYS_TC_CONVERSION_MULTIPLIER / 100000UL)
#define UNIFORM_TIME_DELAY_CTS (UNIFORM_TIME_DELAY * SYS_TC_CONVERSION_MULTIPLIER / 100000UL)

// microseconds to counts
static inline uint64_t us2cts(uint64_t us) {
	return us * SYS_TC_CONVERSION_MULTIPLIER / 100000ULL;
}

// counts to microseconds
static inline uint64_t cts2us(uint64_t cts) {
	return cts * 100000ULL / SYS_TC_CONVERSION_MULTIPLIER;
}


// Main timer/counter for events (module TC1 channel 0)
#define ID_SYS_TC		ID_TC3
#define SYS_TC			TC1		// ID / 3
#define SYS_TC_CH		0		// ID % 3
#define SYS_TC_Handler  TC3_Handler
#define SYS_TC_IRQn		TC3_IRQn

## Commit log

2025-08-25 Added Arduino Due schematic document
2025-08-25 microsync.py: Event visualization - group events by pin, show high/low states
2025-08-27 Bugfix in pTIRF ALEX/strobo mode with incorrect camera readout time
    [globals.h]
2025-08-28 Added `plot_event_file` function to visualize events saved into a file. Converted time units to milliseconds.
2025-08-28 EventVisualizer now uses milliseconds; minor bug fix
2025-09-03 Added rw_CAM_GLOBAL_RESET property in firmware and in Python class for camera global reset functionality
    [globals.h]
2025-09-04 Refactored pTIRF acquisition modes to use new property global camera reset in level trigger mode
2025-09-12 Updated README and diagrams to reflect changes in camera level trigger mode properties, replacing global reset references with specific mode settings for Kinetix and Hamamatsu cameras. Adjusted code 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
    [globals.h]
2025-09-22 Main loop execution is indicated by debug pin instead of error pin.
    [globals.h, main.cpp]
2025-10-08 v2.5.1: new property for camera level triggering modes
2025-10-08 Disabled pull-up resistor for interlock IN pin
2025-10-09 Fixes #1 - Pin D4 is hardwired to PA29 and PC26. Disabled PC26. Revoked control over D0 and D1 (used by UART).
    [globals.h]
2025-10-09 Error LED stays on until the event queue is cleared. Debug and error pins are unavailable.
    [main.cpp, uart_comm.cpp]
2025-10-09 Implement validation for pin names in event scheduling functions and update error handling. The pin_name_to_ioport_id function now returns INVALID_PIN_IDX for invalid pin names, triggering error LED 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
2025-10-09 Fixed D10 pin hardwired to both PA28 and PC29 - disabled PC29 pin
2025-10-09 Annotated 3mA max pins
2025-10-10 Updated build_release to correctly handle different version numbers of driver and firmware
2025-10-23 Updated docs to reflect the pin change in v2.6.0. Disabled pins D35-D38 - inputs for future use.
2025-10-23 Changed pinout definitions to match microsync PCB v0.2
2025-10-23 v2.6 for microsync PCB v0.2 - changed pin definitions! Changed behavior of error LED; fixed bug with pins D4 and D10.
    [globals.h, main.cpp, uart_comm.cpp]
2025-11-11 Added automatic testing of jitter using Tektronix TDS2000 scope
2025-11-11 update develop (automatic jitter testing)
2025-11-20 Added interlock operating diagrams
    [interlock.kicad_pcb, interlock.kicad_sch]
2025-11-20 Updated some docs
    [data packet structure.xlsx, special pins.xlsx]
2025-11-20 Changed logic of interlock heartbeat sensing to account for cable capacitance
    [data packet structure.xlsx, interlock.kicad_pcb, interlock.kicad_sch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]
2025-12-29 v2.6.2 release: lots of minor improvements and bugfixes * ALEX mode wasn't working when `rw_CAM_LEVEL_TRIGGER_MODE==LVL_TRG_NORMAL` * `N_frames_left()` was always returning 0
    [globals.h]
2026-01-06 Bugfix: max open shutter duration was limited by 71 minutes 35 seconds. No limit anymore
    [globals.h]
2026-02-06 python driver version bump
